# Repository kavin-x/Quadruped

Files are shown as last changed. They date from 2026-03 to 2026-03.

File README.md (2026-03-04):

# 🐕 In-House High-Performance Quadruped Robot

## 📌 Project Overview

This project focuses on the design and development of a **high-performance quadruped robotic dog**, built entirely in-house with a strong emphasis on modularity, efficiency, and scalability.

The system is built around custom motor control electronics using the **STM32G431CBU6** microcontroller, implementing advanced **Field Oriented Control (FOC)** and real-time **CAN FD communication** between joints.

Our goal is to design and develop every critical subsystem internally — including actuator electronics, firmware architecture, communication stack, and mechanical integration.

---

## 🎯 Objectives

- Develop high-efficiency FOC-based motor control
- Design modular smart actuators
- Implement deterministic real-time CAN FD communication
- Build scalable firmware architecture for multi-joint control
- Optimize for performance, responsiveness, and energy efficiency
- Maintain complete in-house system ownership and understanding

---

## 🧠 System Architecture

### 🔹 Control Electronics
- Microcontroller: STM32G431CBU6
- Advanced timer-based PWM generation
- Inline / low-side current sensing
- High-speed ADC sampling
- CAN FD communication interface

### 🔹 Motor Control
- Field Oriented Control (FOC)
- High switching frequency PWM
- Real-time current control loop
- Velocity and position control loops
- Optimized for low latency and high torque response

### 🔹 Communication
- CAN FD based multi-node architecture
- Deterministic joint-level communication
- Scalable bus structure for 12+ actuators
- Distributed-ready control design

### 🔹 Mechanical Design
- Modular actuator units
- Custom motor driver PCB
- Compact, serviceable architecture
- Strength-to-weight optimized structure

---

## 📂 Repository Structure
/firmware
/motor_control
/can_fd
/drivers
/middleware

/hardware
/pcb_design
/schematics
/bom

/mechanical
/cad_files
/actuator_design

/docs
/progress_reports
/architecture_notes

---

## 🚀 Current Progress

- ✅ Custom motor driver PCB designed
- ✅ STM32G431 bring-up completed
- ✅ PWM generation validated
- ✅ ADC sampling verified
- ✅ Initial FOC implementation tested
- 🔄 CAN FD communication framework in progress
- 🔄 Multi-joint synchronization under development
- 🔄 Actuator mechanical refinement ongoing

---

## 🔜 Next Steps

- Complete closed-loop position control
- Optimize FOC loop timing and stability
- Finalize CAN FD protocol structure
- Integrate multiple actuators
- Begin quadruped gait testing
- Implement high-level motion control layer

---

## 🛠️ Development Tools

- STM32CubeIDE
- STM32 HAL / LL Drivers
- Custom FOC algorithms
- Oscilloscope and logic analyzer for validation
- CAN FD debugging tools

---

## 📈 Long-Term Vision

- Fully autonomous quadruped platform
- Advanced locomotion algorithms
- Real-time state estimation
- AI-assisted gait optimization
- Expandable research and development platform

---

## 🤝 Contribution

This is currently an in-house development project.  
Documentation and structured releases will be improved progressively.

---

## 📜 License

License information will be added soon.

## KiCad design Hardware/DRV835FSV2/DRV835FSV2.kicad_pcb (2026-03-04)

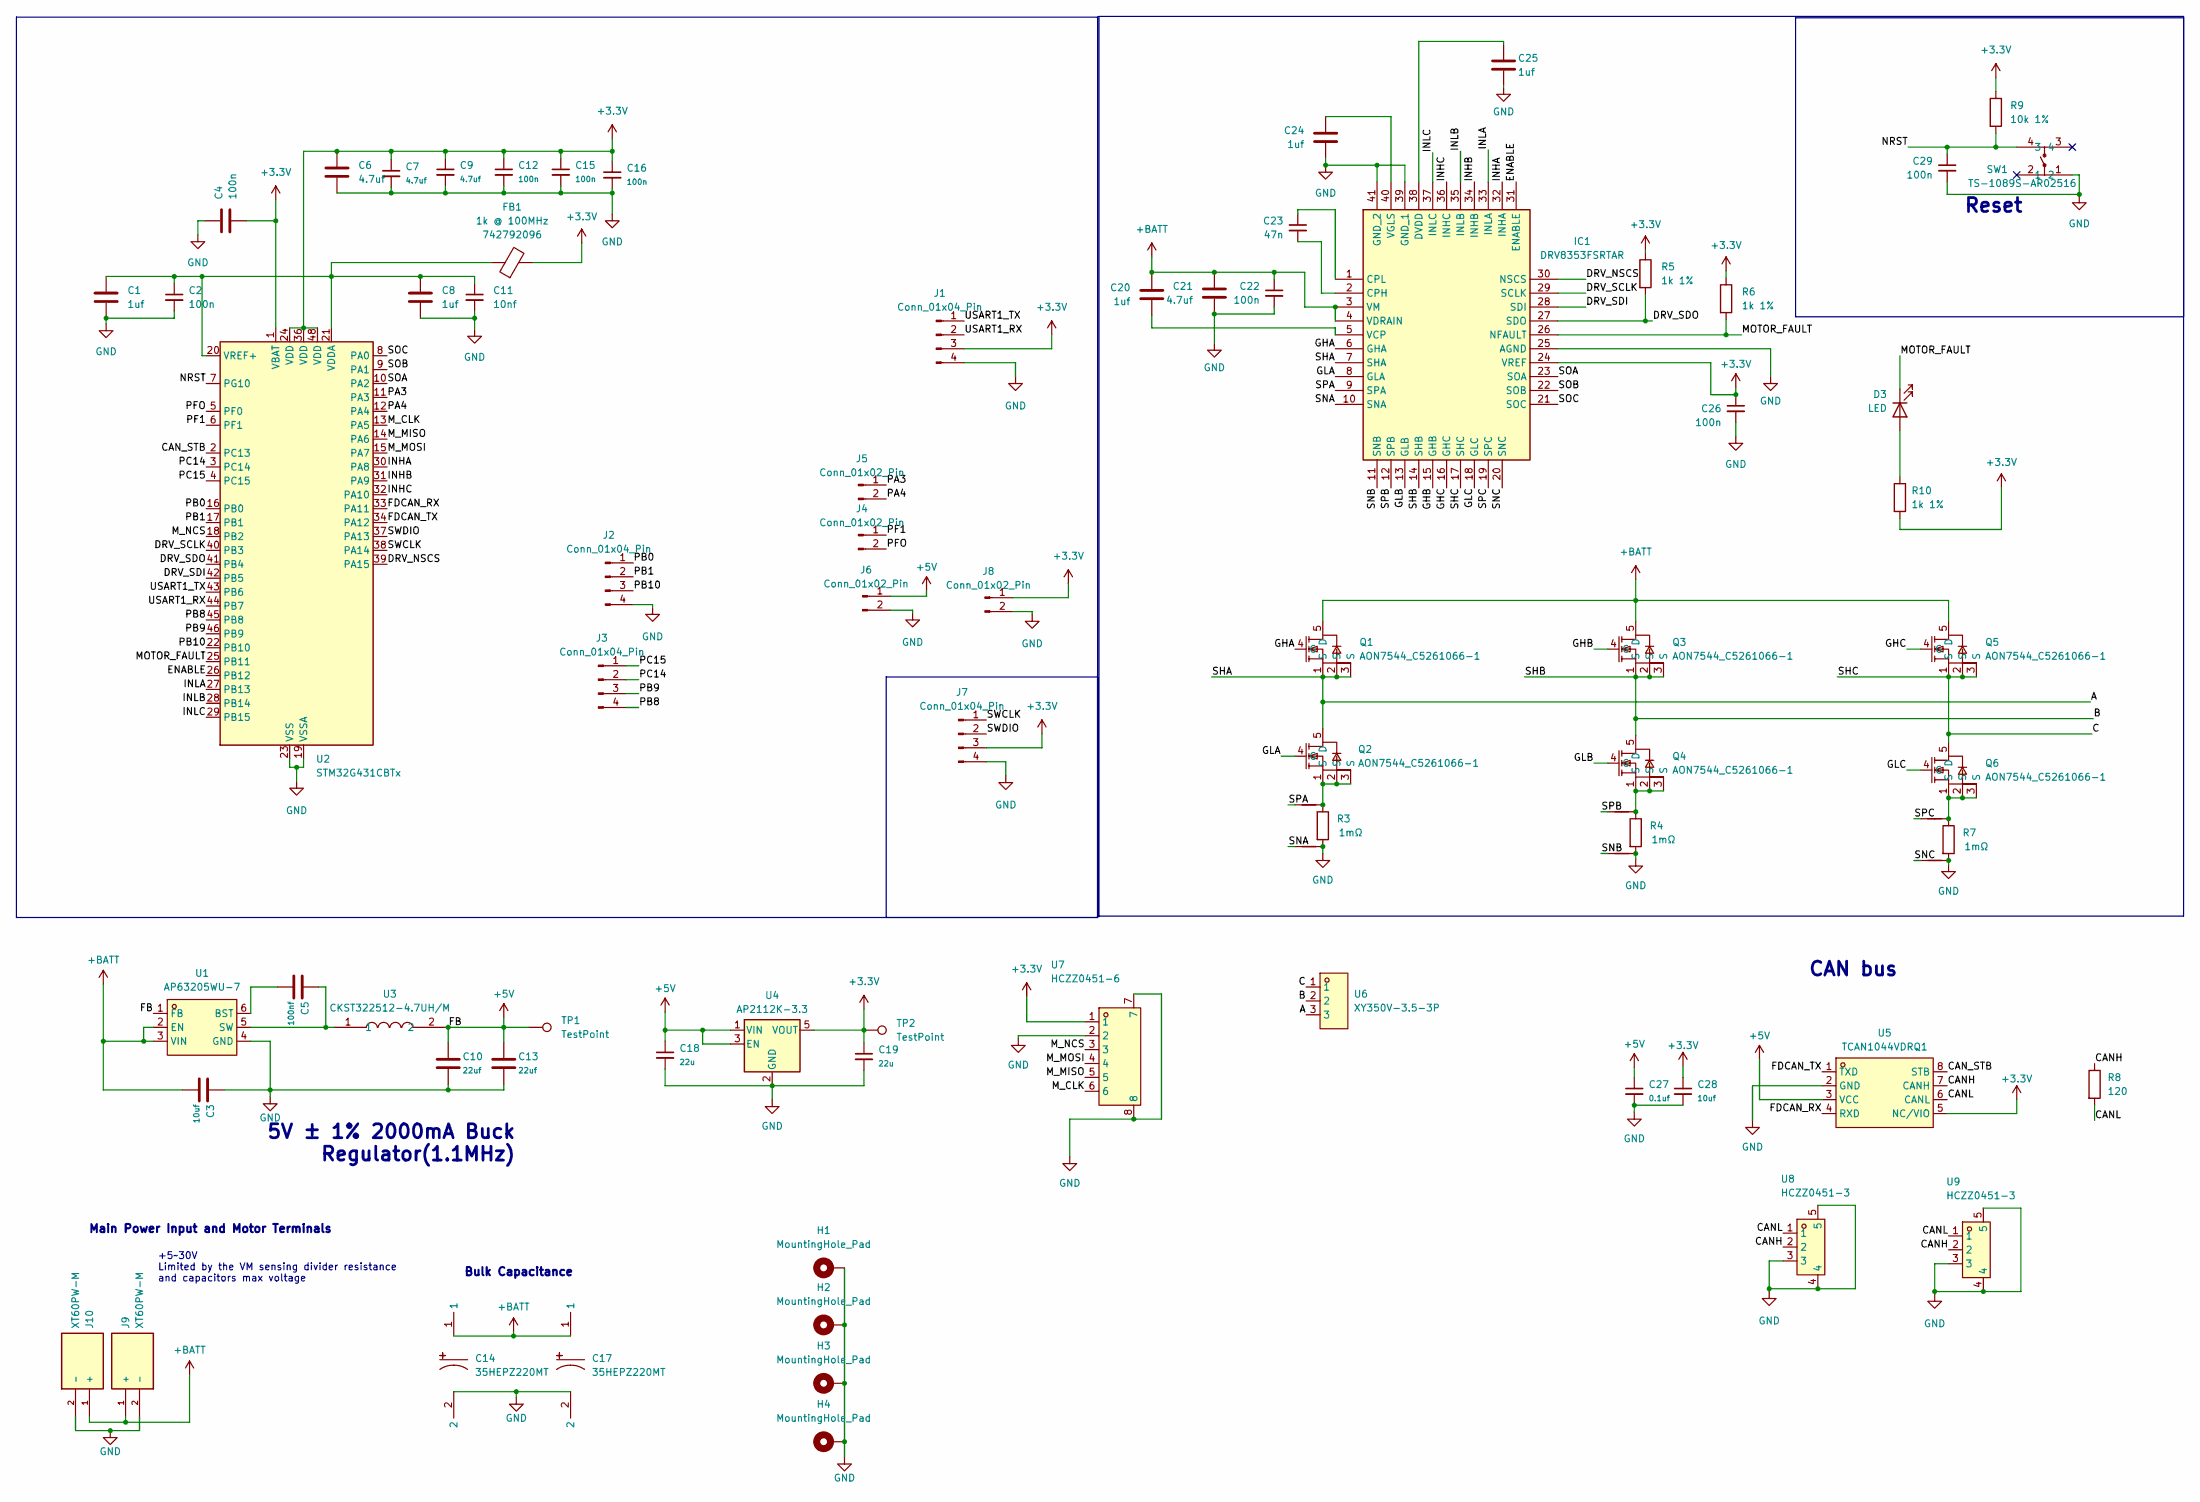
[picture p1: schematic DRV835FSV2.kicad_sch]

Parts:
C1: 1uf; C_0603_1608Metric; Manufacturer Part Number 04023D475MAT2A
C2, C12, C15, C16: 100n; C_0603_1608Metric; Manufacturer Part Number GCM155R71H104KE02J
C3: 10uf; C_0603_1608Metric; Manufacturer Part Number CGA4J1X7R2A225K125AC
C4: 100n; C_0603_1608Metric; Manufacturer Part Number GRM155Z71A105KE01J
C5: 100nf; C_0603_1608Metric; Manufacturer Part Number CGA4J1X7R2A225K125AC
C6: 4.7uf; C_0603_1608Metric; Manufacturer Part Number GRM188Z71C475KE21J
C7, C9: 4.7uf; C_0603_1608Metric; Manufacturer Part Number GCM155R71H104KE02J
C8: 1uf; C_0603_1608Metric; Manufacturer Part Number GRM155Z71A105KE01J
C10: 22uf; C_0603_1608Metric; Manufacturer Part Number GCM155R71H104KE02J
C11: 10nf; C_0603_1608Metric; Manufacturer Part Number GCM155R71H104KE02J
C13: 22uf; C_0603_1608Metric; Manufacturer Part Number GRM21BZ71A226ME15L
C14, C17: 35HEPZ220MT; CAP-TH_BD10.0-P5.00-D1.0-FD; LCSC Part C242064
C18, C19: 22u; C_0603_1608Metric; Manufacturer Part Number GCM155R71H104KE02J
C20, C24: 1uf; C_0603_1608Metric; Manufacturer Part Number TMK107AB7105KAHT
C21: 4.7uf; C_1206_3216Metric; Manufacturer Part Number GRJ31CZ72A475KE01L
C22: 100n; C_0603_1608Metric; Manufacturer Part Number HMK107B7104KAHT
C23: 47n; C_0603_1608Metric; Manufacturer Part Number C0603C473K1RECAUTO
C25: 1uf; C_0603_1608Metric; Manufacturer Part Number GRT155R70J105KE01D
C26: 100n; C_0603_1608Metric; Manufacturer Part Number GCM155R71C104KA55D
C27: 0.1uf; C_0603_1608Metric; Manufacturer Part Number GCM155R71H104KE02J
C28: 10uf; C_0603_1608Metric; Manufacturer Part Number GCM155R71H104KE02J
C29: 100n; C_0603_1608Metric; Manufacturer Part Number C0603C473K1RECAUTO
D3: LED; C_0603_1608Metric
FB1: 1k @ 100MHz; R_0603_1608Metric_Pad0.98x0.95mm_HandSolder; Manufacturer Part Number 742792096; LCSC Part C85824
H1, H2, H3, H4: MountingHole_Pad; MountingHole_2.7mm_Pad_Via
IC1: DRV8353FSRTAR; WQFN-40_L6.0-W6.0-P0.50-TL-EP4.5; Manufacturer_Part_Number DRV8353FSRTAR; Mouser Part Number 595-DRV8353FSRTAR
J1, J2, J3, J7: Conn_01x04_Pin; PinHeader_1x04_P2.54mm_Vertical
J4, J5, J6, J8: Conn_01x02_Pin; PinHeader_1x02_P2.54mm_Vertical
J9, J10: XT60PW-M; AMASS_XT60PW-M; PARTREV V1.2
NT1, NT2, NT3, NT4, NT5, NT6: NetTie_2; NetTie-2_SMD_Pad0.5mm
Q1, Q2, Q3, Q4, Q5, Q6: AON7544_C5261066-1; POWERDI3333-8_L3.3-W3.3-P0.65-BL; LCSC Part C5261066
R3, R4, R7: 1mΩ; R_2512_6332Metric; MFR.Part # ASR-M-3-0.5F; JLCPCB Part # C469426
R5, R6: 1k 1%; R_0603_1608Metric; Manufacturer Part Number ERJ-2RKF2001X; LCSC Part C21190
R8: 120; R_0603_1608Metric; Manufacturer Part Number ERJ-2RKF2001X; LCSC Part C21190
R9: 10k 1%; R_0603_1608Metric; Manufacturer Part Number ERJ-2RKF2001X; LCSC Part C25804
R10: 1k 1%; R_0603_1608Metric; Manufacturer Part Number ERJ-2RKF2001X; LCSC Part C25804
SW1: TS-1089S-AR02516; SW-SMD_4P-L4.2-W3.3-P2.15-LS5.1; LCSC Part C720479
TP1, TP2: TestPoint; TestPoint_Pad_D1.0mm
U1: AP63205WU-7; TSOT-23-6_L2.9-W1.6-P0.95-LS2.8-BL; LCSC Part C2071056
U2: STM32G431CBTx; LQFP-48_7x7mm_P0.5mm; LCSC Part C529355
U3: CKST322512-4.7UH/M; MGAH06034R7M-10; LCSC Part C3002560
U4: AP2112K-3.3; SOT-23-5; LCSC Part C51118
U5: TCAN1044VDRQ1; SOIC-8_L4.9-W3.9-P1.27-LS6.0-BL; LCSC Part C1852061
U6: XY350V-3.5-3P; CONN-TH_XY350V-3.5-3P; LCSC Part C557655
U7: HCZZ0451-6; CONN-SMD_HCZZ0451-6; LCSC Part C7433652
U8, U9: HCZZ0451-3; CONN-SMD_3P-P2.00_HCZZ0451-3_1; LCSC Part C7433649

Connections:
+3.3V: C4.2, C6.1, C7.1, C9.1, C12.1, C15.1, C16.1, C19.1, C26.1, C28.1, FB1.2, IC1.24 (VREF), J1.3, J7.3, J8.1, R5.1, R6.1, R9.1, R10.2, TP2.1, U2.1 (VBAT), U2.24 (VDD), U2.36 (VDD), U2.48 (VDD), U4.5 (VOUT), U5.5 (NC/VIO), U7.1
+5V: C10.1, C13.1, C18.1, C27.1, J6.1, TP1.1, U1.1 (FB), U3.2, U4.1 (VIN), U4.3 (EN), U5.3 (VCC)
+BATT: C3.2, C14.1, C17.1, C20.1, C21.1, C22.1, IC1.3 (VM), IC1.4 (VDRAIN), J9.1 (+), J10.1 (+), Q1.5 (D), Q3.5 (D), Q5.5 (D), U1.2 (EN), U1.3 (VIN)
/A: IC1.7 (SHA), Q1.1 (S), Q1.2 (S), Q1.3 (S), Q2.5 (D), U6.3
/B: IC1.14 (SHB), Q3.1 (S), Q3.2 (S), Q3.3 (S), Q4.5 (D), U6.2
/C: IC1.17 (SHC), Q5.1 (S), Q5.2 (S), Q5.3 (S), Q6.5 (D), U6.1
/CANH: R8.1, U5.7 (CANH), U8.2, U9.2
/CANL: R8.2, U5.6 (CANL), U8.1, U9.1
/CAN_STB: U2.2 (PC13), U5.8 (STB)
/DRV_NSCS: IC1.30 (NSCS), U2.39 (PA15)
/DRV_SCLK: IC1.29 (SCLK), U2.40 (PB3)
/DRV_SDI: IC1.28 (SDI), U2.42 (PB5)
/DRV_SDO: IC1.27 (SDO), R5.2, U2.41 (PB4)
/ENABLE: IC1.31 (ENABLE), U2.26 (PB12)
/FDCAN_RX: U2.33 (PA11), U5.4 (RXD)
/FDCAN_TX: U2.34 (PA12), U5.1 (TXD)
/GHA: IC1.6 (GHA), Q1.4 (G)
/GHB: IC1.15 (GHB), Q3.4 (G)
/GHC: IC1.16 (GHC), Q5.4 (G)
/GLA: IC1.8 (GLA), Q2.4 (G)
/GLB: IC1.13 (GLB), Q4.4 (G)
/GLC: IC1.18 (GLC), Q6.4 (G)
/INHA: IC1.32 (INHA), U2.30 (PA8)
/INHB: IC1.34 (INHB), U2.31 (PA9)
/INHC: IC1.36 (INHC), U2.32 (PA10)
/INLA: IC1.33 (INLA), U2.27 (PB13)
/INLB: IC1.35 (INLB), U2.28 (PB14)
/INLC: IC1.37 (INLC), U2.29 (PB15)
/MOTOR_FAULT: D3.1 (K), IC1.26 (NFAULT), R6.2, U2.25 (PB11)
/M_CLK: U2.13 (PA5), U7.6
/M_MISO: U2.14 (PA6), U7.5
/M_MOSI: U2.15 (PA7), U7.4
/M_NCS: U2.18 (PB2), U7.3
/NRST: C29.1, R9.2, SW1.4, U2.7 (PG10)
/PA3: J5.1, U2.11 (PA3)
/PA4: J5.2, U2.12 (PA4)
/PB0: J2.1, U2.16 (PB0)
/PB1: J2.2, U2.17 (PB1)
/PB8: J3.4, U2.45 (PB8)
/PB9: J3.3, U2.46 (PB9)
/PB10: J2.3, U2.22 (PB10)
/PC14: J3.2, U2.3 (PC14)
/PC15: J3.1, U2.4 (PC15)
/PF1: J4.1, U2.6 (PF1)
/PFO: J4.2, U2.5 (PF0)
/SNA: IC1.10 (SNA), NT2.1
/SNB: IC1.11 (SNB), NT4.1
/SNC: IC1.20 (SNC), NT6.1
/SOA: IC1.23 (SOA), U2.10 (PA2)
/SOB: IC1.22 (SOB), U2.9 (PA1)
/SOC: IC1.21 (SOC), U2.8 (PA0)
/SPA: IC1.9 (SPA), NT1.1
/SPB: IC1.12 (SPB), NT3.1
/SPC: IC1.19 (SPC), NT5.1
/SWCLK: J7.1, U2.38 (PA14)
/SWDIO: J7.2, U2.37 (PA13)
/USART1_RX: J1.2, U2.44 (PB7)
/USART1_TX: J1.1, U2.43 (PB6)
GND: C1.2, C2.2, C3.1, C4.1, C6.2, C7.2, C8.2, C9.2, C10.2, C11.2, C12.2, C13.2, C14.2, C15.2, C16.2, C17.2, C18.2, C19.2, C21.2, C22.2, C24.2, C25.2, C26.2, C27.2, C28.2, C29.2, H1.1, H2.1, H3.1, H4.1, IC1.25 (AGND), IC1.39 (GND_1), IC1.41 (GND_2), J1.4, J2.4, J6.2, J7.4, J8.2, J9.2 (-), J10.2 (-), NT2.2, NT4.2, NT6.2, R3.2, R4.2, R7.2, SW1.1, U1.4 (GND), U2.19 (VSSA), U2.23 (VSS), U2.35 (VSS), U2.47 (VSS), U4.2 (GND), U5.2 (GND), U7.2, U7.7, U7.8, U8.3, U8.4, U8.5, U9.3, U9.4, U9.5
unnamed: D3.2 (A), R10.1
unnamed: C23.2, IC1.2 (CPH)
unnamed: C23.1, IC1.1 (CPL)
unnamed: C25.1, IC1.38 (DVDD)
unnamed: C20.2, IC1.5 (VCP)
unnamed: C24.1, IC1.40 (VGLS)
unnamed: NT1.2, Q2.1 (S), Q2.2 (S), Q2.3 (S), R3.1
unnamed: NT3.2, Q4.1 (S), Q4.2 (S), Q4.3 (S), R4.1
unnamed: NT5.2, Q6.1 (S), Q6.2 (S), Q6.3 (S), R7.1
unnamed: C5.2, U1.6 (BST)
unnamed: C5.1, U1.5 (SW), U3.1
unnamed: C1.1, C2.1, C8.1, C11.1, FB1.1, U2.20 (VREF+), U2.21 (VDDA)

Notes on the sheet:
Reset
CAN bus
5V ± 1% 2000mA Buck Regulator(1.1MHz)
+5~30V Limited by the VM sensing divider resistance and capacitors max voltage
Main Power Input and Motor Terminals
Bulk Capacitance

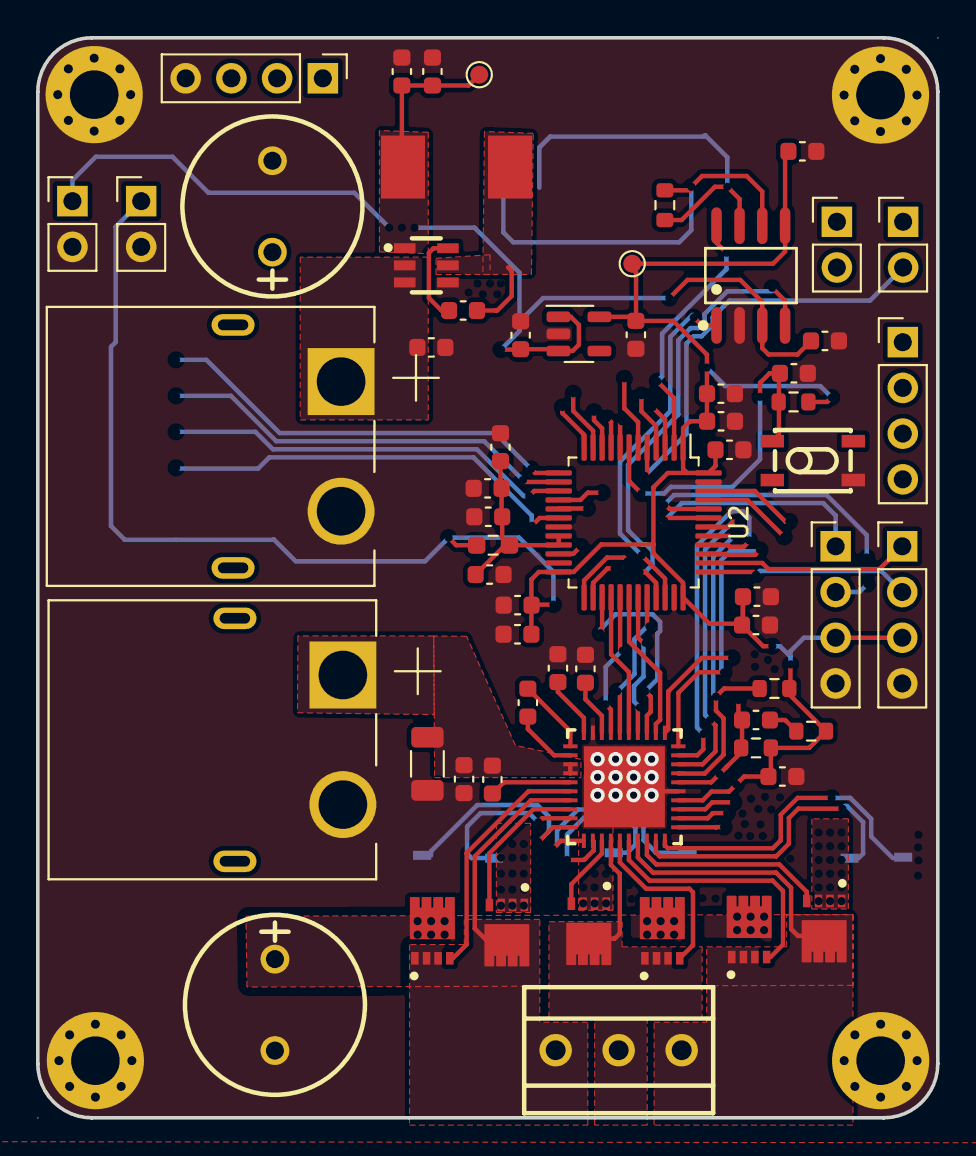
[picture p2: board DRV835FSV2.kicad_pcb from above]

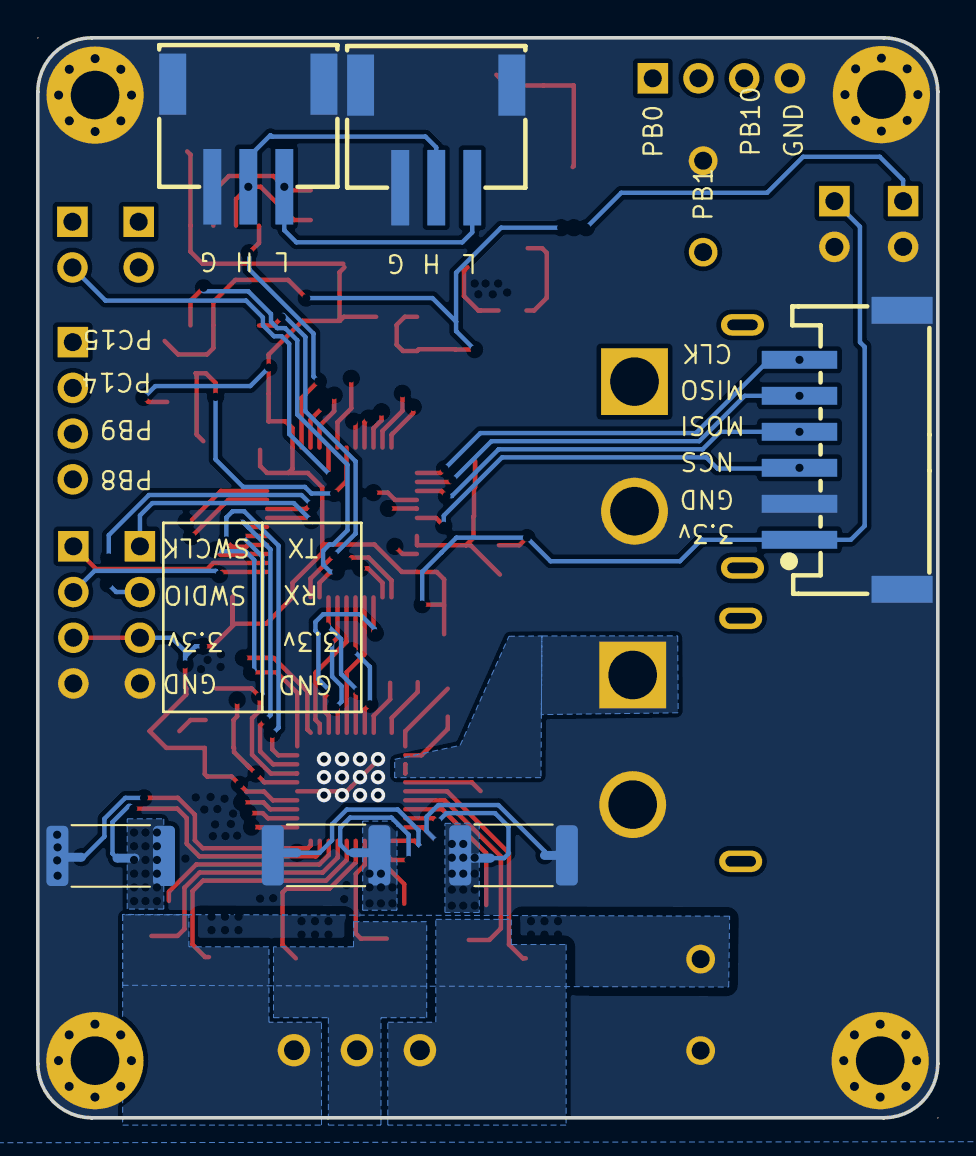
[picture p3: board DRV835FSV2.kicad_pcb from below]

Board: 4 copper layers, 50.0 x 60.0 mm, 78 parts (12 on the bottom side), 71 nets.
